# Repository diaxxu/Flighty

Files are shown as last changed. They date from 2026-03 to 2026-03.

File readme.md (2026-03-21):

flighty_wordmark<svg width="100%" viewBox="0 0 680 160" xmlns="http://www.w3.org/2000/svg"><defs><mask id="imagine-text-gaps-1nc41s" maskUnits="userSpaceOnUse"><rect x="0" y="0" width="680" height="160" fill="white"/><rect x="60.694801330566406" y="23.187637329101562" width="558.6104125976562" height="111.06857299804688" fill="black" rx="2"/></mask></defs>

  <!-- Speed lines behind text — thin diagonal strokes, left to right, rising -->
  <g stroke="#5DCAA5" stroke-linecap="round" fill="none" style="fill:none;stroke:rgb(93, 202, 165);color:rgb(255, 255, 255);stroke-width:1px;stroke-linecap:round;stroke-linejoin:miter;opacity:1;font-family:&quot;Anthropic Sans&quot;, -apple-system, BlinkMacSystemFont, &quot;Segoe UI&quot;, sans-serif;font-size:16px;font-weight:400;text-anchor:start;dominant-baseline:auto">
    <line x1="60" y1="125" x2="190" y2="55" stroke-width="0.8" opacity="0.18" mask="url(#imagine-text-gaps-1nc41s)" style="fill:none;stroke:rgb(93, 202, 165);color:rgb(255, 255, 255);stroke-width:0.8px;stroke-linecap:round;stroke-linejoin:miter;opacity:0.18;font-family:&quot;Anthropic Sans&quot;, -apple-system, BlinkMacSystemFont, &quot;Segoe UI&quot;, sans-serif;font-size:16px;font-weight:400;text-anchor:start;dominant-baseline:auto"/>
    <line x1="70" y1="132" x2="220" y2="58" stroke-width="0.5" opacity="0.12" mask="url(#imagine-text-gaps-1nc41s)" style="fill:none;stroke:rgb(93, 202, 165);color:rgb(255, 255, 255);stroke-width:0.5px;stroke-linecap:round;stroke-linejoin:miter;opacity:0.12;font-family:&quot;Anthropic Sans&quot;, -apple-system, BlinkMacSystemFont, &quot;Segoe UI&quot;, sans-serif;font-size:16px;font-weight:400;text-anchor:start;dominant-baseline:auto"/>
    <line x1="50" y1="118" x2="170" y2="52" stroke-width="0.4" opacity="0.10" mask="url(#imagine-text-gaps-1nc41s)" style="fill:none;stroke:rgb(93, 202, 165);color:rgb(255, 255, 255);stroke-width:0.4px;stroke-linecap:round;stroke-linejoin:miter;opacity:0.1;font-family:&quot;Anthropic Sans&quot;, -apple-system, BlinkMacSystemFont, &quot;Segoe UI&quot;, sans-serif;font-size:16px;font-weight:400;text-anchor:start;dominant-baseline:auto"/>
    <line x1="460" y1="108" x2="640" y2="40" stroke-width="0.8" opacity="0.18" mask="url(#imagine-text-gaps-1nc41s)" style="fill:none;stroke:rgb(93, 202, 165);color:rgb(255, 255, 255);stroke-width:0.8px;stroke-linecap:round;stroke-linejoin:miter;opacity:0.18;font-family:&quot;Anthropic Sans&quot;, -apple-system, BlinkMacSystemFont, &quot;Segoe UI&quot;, sans-serif;font-size:16px;font-weight:400;text-anchor:start;dominant-baseline:auto"/>
    <line x1="470" y1="118" x2="648" y2="48" stroke-width="0.5" opacity="0.12" mask="url(#imagine-text-gaps-1nc41s)" style="fill:none;stroke:rgb(93, 202, 165);color:rgb(255, 255, 255);stroke-width:0.5px;stroke-linecap:round;stroke-linejoin:miter;opacity:0.12;font-family:&quot;Anthropic Sans&quot;, -apple-system, BlinkMacSystemFont, &quot;Segoe UI&quot;, sans-serif;font-size:16px;font-weight:400;text-anchor:start;dominant-baseline:auto"/>
    <line x1="455" y1="100" x2="630" y2="35" stroke-width="0.4" opacity="0.10" mask="url(#imagine-text-gaps-1nc41s)" style="fill:none;stroke:rgb(93, 202, 165);color:rgb(255, 255, 255);stroke-width:0.4px;stroke-linecap:round;stroke-linejoin:miter;opacity:0.1;font-family:&quot;Anthropic Sans&quot;, -apple-system, BlinkMacSystemFont, &quot;Segoe UI&quot;, sans-serif;font-size:16px;font-weight:400;text-anchor:start;dominant-baseline:auto"/>
  </g>

  <!-- Main wordmark -->
  <text x="340" y="112" text-anchor="middle" font-family="'Rajdhani', 'Arial Narrow', sans-serif" font-size="96" font-weight="700" letter-spacing="20" fill="#5DCAA5" style="fill:rgb(93, 202, 165);stroke:none;color:rgb(255, 255, 255);stroke-width:1px;stroke-linecap:butt;stroke-linejoin:miter;opacity:1;font-family:Rajdhani, &quot;Arial Narrow&quot;, sans-serif;font-size:96px;font-weight:700;text-anchor:middle;dominant-baseline:auto"></text>

  <!-- The "I" dot replaced by a small compass rose / crosshair -->
  <!-- crosshair sits over the letter I — centered around x≈340, but "I" is the 5th letter -->
  <!-- We use a tiny crosshair as a decorative accent above the wordmark -->
  <g transform="translate(340, 28)" style="fill:rgb(0, 0, 0);stroke:none;color:rgb(255, 255, 255);stroke-width:1px;stroke-linecap:butt;stroke-linejoin:miter;opacity:1;font-family:&quot;Anthropic Sans&quot;, -apple-system, BlinkMacSystemFont, &quot;Segoe UI&quot;, sans-serif;font-size:16px;font-weight:400;text-anchor:start;dominant-baseline:auto">
    <circle cx="0" cy="0" r="7" fill="none" stroke="#9FE1CB" stroke-width="1" style="fill:none;stroke:rgb(159, 225, 203);color:rgb(255, 255, 255);stroke-width:1px;stroke-linecap:butt;stroke-linejoin:miter;opacity:1;font-family:&quot;Anthropic Sans&quot;, -apple-system, BlinkMacSystemFont, &quot;Segoe UI&quot;, sans-serif;font-size:16px;font-weight:400;text-anchor:start;dominant-baseline:auto"/>
    <line x1="-12" y1="0" x2="12" y2="0" stroke="#9FE1CB" stroke-width="1" stroke-linecap="round" style="fill:rgb(0, 0, 0);stroke:rgb(159, 225, 203);color:rgb(255, 255, 255);stroke-width:1px;stroke-linecap:round;stroke-linejoin:miter;opacity:1;font-family:&quot;Anthropic Sans&quot;, -apple-system, BlinkMacSystemFont, &quot;Segoe UI&quot;, sans-serif;font-size:16px;font-weight:400;text-anchor:start;dominant-baseline:auto"/>
    <line x1="0" y1="-12" x2="0" y2="12" stroke="#9FE1CB" stroke-width="1" stroke-linecap="round" style="fill:rgb(0, 0, 0);stroke:rgb(159, 225, 203);color:rgb(255, 255, 255);stroke-width:1px;stroke-linecap:round;stroke-linejoin:miter;opacity:1;font-family:&quot;Anthropic Sans&quot;, -apple-system, BlinkMacSystemFont, &quot;Segoe UI&quot;, sans-serif;font-size:16px;font-weight:400;text-anchor:start;dominant-baseline:auto"/>
    <circle cx="0" cy="0" r="2" fill="#5DCAA5" style="fill:rgb(93, 202, 165);stroke:none;color:rgb(255, 255, 255);stroke-width:1px;stroke-linecap:butt;stroke-linejoin:miter;opacity:1;font-family:&quot;Anthropic Sans&quot;, -apple-system, BlinkMacSystemFont, &quot;Segoe UI&quot;, sans-serif;font-size:16px;font-weight:400;text-anchor:start;dominant-baseline:auto"/>
  </g>

  <!-- Thin underline with notch — like a runway -->
  <line x1="80" y1="128" x2="600" y2="128" stroke="#1D9E75" stroke-width="1" opacity="0.5" mask="url(#imagine-text-gaps-1nc41s)" style="fill:rgb(0, 0, 0);stroke:rgb(29, 158, 117);color:rgb(255, 255, 255);stroke-width:1px;stroke-linecap:butt;stroke-linejoin:miter;opacity:0.5;font-family:&quot;Anthropic Sans&quot;, -apple-system, BlinkMacSystemFont, &quot;Segoe UI&quot;, sans-serif;font-size:16px;font-weight:400;text-anchor:start;dominant-baseline:auto"/>
  <line x1="316" y1="128" x2="364" y2="128" stroke="#9FE1CB" stroke-width="2.5" stroke-linecap="round" opacity="0.9" mask="url(#imagine-text-gaps-1nc41s)" style="fill:rgb(0, 0, 0);stroke:rgb(159, 225, 203);color:rgb(255, 255, 255);stroke-width:2.5px;stroke-linecap:round;stroke-linejoin:miter;opacity:0.9;font-family:&quot;Anthropic Sans&quot;, -apple-system, BlinkMacSystemFont, &quot;Segoe UI&quot;, sans-serif;font-size:16px;font-weight:400;text-anchor:start;dominant-baseline:auto"/>

  <!-- Tiny dots at ends of underline -->
  <circle cx="80" cy="128" r="2" fill="#1D9E75" opacity="0.5" style="fill:rgb(29, 158, 117);stroke:none;color:rgb(255, 255, 255);stroke-width:1px;stroke-linecap:butt;stroke-linejoin:miter;opacity:0.5;font-family:&quot;Anthropic Sans&quot;, -apple-system, BlinkMacSystemFont, &quot;Segoe UI&quot;, sans-serif;font-size:16px;font-weight:400;text-anchor:start;dominant-baseline:auto"/>
  <circle cx="600" cy="128" r="2" fill="#1D9E75" opacity="0.5" style="fill:rgb(29, 158, 117);stroke:none;color:rgb(255, 255, 255);stroke-width:1px;stroke-linecap:butt;stroke-linejoin:miter;opacity:0.5;font-family:&quot;Anthropic Sans&quot;, -apple-system, BlinkMacSystemFont, &quot;Segoe UI&quot;, sans-serif;font-size:16px;font-weight:400;text-anchor:start;dominant-baseline:auto"/>
</svg>

**Flighty** is my very first custom-designed flight controller! I built this to be a versatile "brain" for just about anything that flies, from standard quadcopters and fixed-wing UAVs to high-power model rockets.

I am currently using this board to power my personal RC VTOL project. It’s designed to be easy to solder (THT components), easy to repair, and a great hands-on project for anyone interested in PCB assembly.

##  Key Features

* **7x Servo/PWM Channels:** Plenty of outputs for complex RC planes, hexacopters, or VTOL transitions.
* **Rocketry Ready:** Two dedicated channels can be configured as electronic igniters (pyro-channels) for rocket motor ignition or parachute deployment.
* **Blackbox Data Logging:** Integrated **MicroSD slot** to record high-speed flight data, allowing you to re-analyze crashes or tune PID loops with precision.
* **Reliable Power Management:** Designed for **2S LiPo/Li-ion** setups with an integrated charging and protection circuit.
* **Repair-Friendly Design:** Focused on Through-Hole Technology (THT) for connectors and key components, making it durable and easy to fix in the field.

##  Hardware

* **Brain (MCU): STM32F405RGT6** – This is the heart of the board. It’s a powerful chip that handles high-frequency flight loops and complex navigation without breaking a sweat.
* **Gyro/Accel: MPU6500** – To keep things stable, I'm using the MPU6500 over I2C. It supports fast refresh rates (up to 500Hz on the bus) to keep the flight feeling smooth and responsive.
* **Altitude (Baro): BMP580** – This sensor is a beast. It’s incredibly precise, detecting altitude changes down to a few centimeters. It's perfect for a rock-steady hover or timing a rocket's parachute deployment at exactly the right moment.
* **Power: TPS63070 (Buck-Boost)** – I wanted to avoid brownouts. This regulator keeps a rock-solid 5V supplied to the sensors and MCU, even if the battery voltage drops during a hard maneuver.
* **Charging: BQ25883** – I added a built-in 2S balancer/charger. This is super convenient because you can top up your batteries directly through the board using the USB port.
* **Plug: USB Type-C** – Because nobody wants to carry around old Micro-USB cables anymore. One cable for your phone, your laptop, and your flight controller.

##  Software & Firmware

Flighty is compatible with **Ardupilot**, **INAV**, and **Betaflight**. 

> **Note:** Because this is a custom hardware layout, you will need to define a custom target (mapping the SPI/UART/PWM pins) in your chosen firmware.

---

##  Gallery

### Schematics
Flighty Schematic

### PCB Design
PCB Layout

### 3D Visuals
3D PCB View
Board Render

---

##  Bill of Materials (BOM)

| Item | Description | Quantity | Unit Price |
| :--- | :--- | :--- | :--- |
| **Flight Controller PCB** | Bare PCB from JLCPCB | 5 | $2.00 |
| **Flight Controller PCBA** | Fully Assembled Board | 2 | $130.71 |

**Project Total: $159.21**

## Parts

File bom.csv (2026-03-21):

Comment | Designator | Footprint | JLCPCB Part #
383 | RR1 | 0603 | C177271
TYPE-C16PIN2MD(073) | USB1 | USB-C-SMD_TYPE-C-6PIN-2MD-073 | C2765186
TF-01A | CARD1 | TF-SMD_TF-01A | C91145
1uF | C1,C26,C27,C28 | 0805 | C28323
LMR51430YFDDCR | U6 | SOT-23-6_L2.9-W1.6-P0.95-LS2.9-BL | C5219261
1uH | L1 | 0805 | C1042
Q13FC1350000400 | X2 | FC-135R_L3.2-W1.5 | C32346
100nF | C21,C22,C20,C31,C32,C33,C34,C35,C21,C22,C20,C31,C32,C33,C34,C35 | 0603 | C14663
MPU6500 | U1 | QFN-24_L3.0-W3.0-P0.40-BL-EP | C50278
2.2uF | C24,C25 | CP_Radial_D4.0mm_P1.50mm | C970595
30.1k | R6 | 0603 | C137745
TPS63070RNMR | U3 | VQFN-15_L3.0-W2.5-P0.50-BL | C109322
5.23k | R7 | 0603 | C2930111
SW_Push | SW1,SW2 | SW_PUSH_6mm | C83205
LED | D1 | 0603 | C2290
X322512MSB4SI | X1 | CRYSTAL-SMD_4P-L3.2-W2.5-BL | C9002
1.5uh | L2 | 0805 | C139220
47uF | C6,C4,C6,C4 | CP_Radial_D8.0mm_P5.00mm | C46895
BMP580 | U4 | LGA-10_L2.0-W2.0-P0.50-TL_BMP580 | C22391138
5.1k | R2,R3 | 0603 | C23186
0.1uF | C15,C19,C30,C7,C23,C15,C19,C30,C7,C23 | 0805 | C49678
22uF | C10,C11,C16,C17,C9 | CP_Radial_D5.0mm_P2.00mm | C43346
FCM1608KF-601T03 | L4 | L0603 | C141723
22.1k | R15 | 0603 | C100870
5.6uH | L3 | 0805 | C307698
STM32F405RGTx | U7 | LQFP-64_10x10mm_P0.5mm | C15742
6.8pF | C36,C37 | 0805 | C1832
Conn_01x03 | J2,J3,J4,J5,J6,J7,J8 | PinHeader_1x03_P2.54mm_Vertical | C49257
4.7k | R16,R17 | 0603 | C23162
10k | R10,R11,R12,R13,R18,R19,R20,R21,R22,R23,R24,R4,R5,R8,R9 | 0603 | C25804
BQ25883RGER | U5 | VFQFPN-24_L4.0-W4.0-P0.50-BL-EP2.8 | C544362
Screw_Terminal_01x02 | J1 | TerminalBlock_Xinya_XY308-2.54-2P_1x02_P2.54mm_Horizontal | C557685
100k | R14 | 0603 | C25803
10uF | C12,C13,C14,C18,C2,C29,C3,C5,C8 | CP_Radial_D5.0mm_P2.00mm | C19576

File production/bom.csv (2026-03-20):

Designator | Footprint | Quantity | Value | LCSC Part #
C1, C26, C27, C28 | 0805 | 4 | 1uF
C10, C11, C16, C17, C9 | CP_Radial_D5.0mm_P2.00mm | 5 | 22uF
C12, C13, C14, C18, C2, C29, C3, C5, C8 | CP_Radial_D5.0mm_P2.00mm | 9 | 10uF
C15, C19, C30, C7 | 0805 | 4 | 100nF
C20, C31, C32, C33, C34, C35 | 0603 | 6 | 100nF
C21, C22 | 0603 | 2 | 0.1uF
C23 | 0805 | 1 | 0.1uF
C24, C25 | CP_Radial_D4.0mm_P1.50mm | 2 | 2.2uF
C36, C37 | 0805 | 2 | 6.8pF
C4 | CP_Radial_D8.0mm_P5.00mm | 1 | 47uF
C6 | CP_Radial_D8.0mm_P5.00mm | 1 | 44uF
CARD1 | TF-SMD_TF-01A | 1 | TF-01A | C91145
D1 | 0603 | 1 | LED
J1 | TerminalBlock_Xinya_XY308-2.54-2P_1x02_P2.54mm_Horizontal | 1 | Screw_Terminal_01x02
J2, J3, J4, J5, J6, J7, J8 | PinHeader_1x03_P2.54mm_Vertical | 7 | Conn_01x03
L1 | 0805 | 1 | 1uH
L2 | 0805 | 1 | 1.5uh
L3 | 0805 | 1 | 5.6uH
L4 | L0603 | 1 | FCM1608KF-601T03 | C141723
R10, R11, R12, R13, R18, R19, R20, R21, R22, R23, R24, R4, R5, R8, R9 | 0603 | 15 | 10k
R14 | 0603 | 1 | 100k
R15 | 0603 | 1 | 22.1k
R16, R17 | 0603 | 2 | 4.7 k
R2, R3 | 0603 | 2 | 5.1k
R6 | 0603 | 1 | 30.1k
R7 | 0603 | 1 | 5.23k
RR1 | 0603 | 1 | 383
SW1, SW2 | SW_PUSH_6mm | 2 | SW_Push
U1 | QFN-24_L3.0-W3.0-P0.40-BL-EP | 1 | MPU6500 | C50278
U3 | VQFN-15_L3.0-W2.5-P0.50-BL | 1 | TPS63070RNMR | C109322
U4 | LGA-10_L2.0-W2.0-P0.50-TL_BMP580 | 1 | BMP580 | C22391138
U5 | VFQFPN-24_L4.0-W4.0-P0.50-BL-EP2.8 | 1 | BQ25883RGER | C544362
U6 | SOT-23-6_L2.9-W1.6-P0.95-LS2.9-BL | 1 | LMR51430YFDDCR | C5219261
U7 | LQFP-64_10x10mm_P0.5mm | 1 | STM32F405RGTx
USB1 | USB-C-SMD_TYPE-C-6PIN-2MD-073 | 1 | TYPE-C 16PIN 2MD(073) | C2765186
X1 | CRYSTAL-SMD_4P-L3.2-W2.5-BL | 1 | X322512MSB4SI | C9002
X2 | FC-135R_L3.2-W1.5 | 1 | Q13FC1350000400 | C32346

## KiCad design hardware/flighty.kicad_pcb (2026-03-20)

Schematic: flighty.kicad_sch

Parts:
C1: 1uF; C_0805_2012Metric
C2, C3, C5, C8, C12, C13, C14, C18: 10uF; CP_Radial_D5.0mm_P2.00mm
C4: 47uF; CP_Radial_D8.0mm_P5.00mm
C6: 44uF; CP_Radial_D8.0mm_P5.00mm
C7, C15, C19, C30: 100nF; C_0805_2012Metric
C9, C10, C11, C16, C17: 22uF; CP_Radial_D5.0mm_P2.00mm
C20, C31, C32, C33, C34, C35: 100nF; C_0603_1608Metric
C21, C22: 0.1uF; C_0603_1608Metric
C23: 0.1uF; C_0805_2012Metric
C24, C25: 2.2uF; CP_Radial_D4.0mm_P1.50mm
C26, C27, C28: 1uf; C_0805_2012Metric
C29: 10uf; CP_Radial_D5.0mm_P2.00mm
C36, C37: 6.8pF; C_0805_2012Metric
Card1: TF-01A; TF-SMD_TF-01A; LCSC Part C91145
D1: LED; LED_0603_1608Metric
J1: Screw_Terminal_01x02; TerminalBlock_Xinya_XY308-2.54-2P_1x02_P2.54mm_Horizontal
J2, J3, J4, J5, J6, J7, J8: Conn_01x03; PinHeader_1x03_P2.54mm_Vertical
L1: 1uH; L_0805_2012Metric
L2: 1.5uh; L_0805_2012Metric
L3: 5.6uH; L_0805_2012Metric
L4: FCM1608KF-601T03; L0603; LCSC Part C141723
R2, R3: 5.1k; R_0603_1608Metric
R4, R8, R9, R10, R11, R12, R24: 10k; R_0603_1608Metric
R5, R13, R18, R19, R20, R21, R22, R23: 10K; R_0603_1608Metric
R6: 30.1k; R_0603_1608Metric
R7: 5.23k; R_0603_1608Metric
R14: 100k; R_0603_1608Metric
R15: 22.1k; R_0603_1608Metric
R16, R17: 4.7 k; R_0603_1608Metric
RR1: 383; R_0603_1608Metric
SW1, SW2: SW_Push; SW_PUSH_6mm
U1: MPU6500; QFN-24_L3.0-W3.0-P0.40-BL-EP; LCSC Part C50278
U3: TPS63070RNMR; VQFN-15_L3.0-W2.5-P0.50-BL; LCSC Part C109322
U4: BMP580; LGA-10_L2.0-W2.0-P0.50-TL_BMP580; LCSC Part C22391138
U5: BQ25883RGER; VFQFPN-24_L4.0-W4.0-P0.50-BL-EP2.8; LCSC Part C544362
U6: LMR51430YFDDCR; SOT-23-6_L2.9-W1.6-P0.95-LS2.9-BL; LCSC Part C5219261
U7: STM32F405RGTx; LQFP-64_10x10mm_P0.5mm
USB1: TYPE-C 16PIN 2MD(073); USB-C-SMD_TYPE-C-6PIN-2MD-073; LCSC Part C2765186
X1: X322512MSB4SI; CRYSTAL-SMD_4P-L3.2-W2.5-BL; LCSC Part C9002
X2: Q13FC1350000400; FC-135R_L3.2-W1.5; LCSC Part C32346

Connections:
+3.3V: C16.1, C17.1, C19.1, C20.1, C21.2, C22.2, C26.1, C27.1, C28.1, C29.1, C30.1, C31.1, C32.1, C33.1, C34.1, Card1.4 (VDD), L3.2, L4.2, R16.1, R17.1, R18.1, R19.1, R20.1, R21.1, R22.1, R23.1, SW2.2, U1.8 (VDDIO), U1.9 (SDO/AD0), U1.13 (VDD), U1.22 (nCS), U4.1 (VDDIO), U4.10 (VDD), U7.1 (VBAT), U7.19 (VDD), U7.32 (VDD), U7.48 (VDD), U7.64 (VDD)
+5V: C8.2, C9.2, C10.2, C11.2, J2.2, J3.2, J4.2, J5.2, J6.2, J7.2, J8.2, R5.2, R8.1, U3.5 (FB), U3.7 (Vout), U3.8 (Vout)
+BATT: C5.1, J1.1, U5.13 (BAT), U5.14 (BAT)
/BMP_INT: U4.7 (INT), U7.36 (PB15)
/BMP_SCL: U4.2 (SCK), U7.58 (PB6)
/BMP_SDA: U4.4 (SDI), U7.59 (PB7)
/BQ_CE: U5.3 (~CE), U7.37 (PC6)
/BQ_INT: R10.2, U5.6 (~INT), U7.38 (PC7)
/BQ_PG: R8.2, U5.9 (~PG)
/BQ_SCL: R11.2, U5.5 (SCL)
/BQ_SDA: R12.2, U5.4 (SDA)
/BTST: C4.1, L1.2, U5.17 (SW), U5.18 (SW)
/MPU_INT: U1.12 (INT), U7.35 (PB14)
/MPU_SCL: R17.2, U1.23 (SCL/SCLK), U7.29 (PB10)
/MPU_SDA: R16.2, U1.24 (SDA/SDI), U7.30 (PB11)
/SD_CD: Card1.9 (CD)
/SD_CLK: Card1.5 (CLK(SCLK)), R23.2, U7.53 (PC12)
/SD_CMD: Card1.3 (CMD(DI)), R22.2, U7.54 (PD2)
/SD_DAT0: Card1.7 (DAT0(D0)), R21.2, U7.39 (PC8)
/SD_DAT1: Card1.8 (DAT1(RSV)), R20.2, U7.40 (PC9)
/SD_DAT2: Card1.1 (DAT2(RSV)), R19.2, U7.51 (PC10)
/SD_DAT3: Card1.2 (CDDAT3(CS)), R18.2, U7.52 (PC11)
/SERVO_1: J3.1, U7.61 (PB8)
/SERVO_2: J2.1, U7.62 (PB9)
/SERVO_3: J4.1, U7.55 (PB3)
/SERVO_4: J5.1, U7.16 (PA2)
/SERVO_5: J6.1, U7.17 (PA3)
/SERVO_6: J7.1, U7.21 (PA5)
/SERVO_7: J8.1, U7.22 (PA6)
/USB_DN: U7.44 (PA11), USB1.5 (DN2), USB1.7 (DN1)
/USB_DP: U7.45 (PA12), USB1.6 (DP1), USB1.8 (DP2)
/USB_vbus: USB1.2 (VBUS), USB1.11 (VBUS)
GND: C2.2, C3.2, C5.2, C6.2, C7.1, C8.1, C9.1, C10.1, C11.1, C12.1, C13.1, C14.1, C16.2, C17.2, C18.2, C19.2, C20.2, C21.1, C22.1, C23.1, C24.1, C25.1, C26.2, C27.2, C28.2, C29.2, C30.2, C31.2, C32.2, C33.2, C34.2, C36.1, C37.2, Card1.6 (VSS), Card1.10 (GND), Card1.11 (GND), J2.3, J3.3, J4.3, J5.3, J6.3, J7.3, J8.3, R2.1, R3.1, R4.2, R6.2, R15.2, R24.1, RR1.2, SW1.1, U1.11 (FSYNC), U1.18 (GND), U3.4 (GND), U3.6 (FB2), U3.10 (PGND), U3.15 (Vsel), U4.3 (VSS), U4.5 (SDO), U4.6 (CSB), U4.8 (VSS), U4.9 (VSS), U5.19 (GND), U5.20 (GND), U6.1 (GND), U7.12 (VSSA), U7.18 (VSS), U7.63 (VSS), USB1.1 (GND), USB1.12 (GND), USB1.13 (SHELL), USB1.14 (SHELL), X1.2 (GND), X1.4 (GND)
unnamed: C2.1, L1.1, U5.21 (PMID), U5.22 (PMID)
unnamed: C35.1, SW1.2
unnamed: D1.2 (A), R9.1
unnamed: D1.1 (K), U5.2 (STAT)
unnamed: R9.2, R10.1, R11.1, R12.1
unnamed: C23.2, U1.10 (REGOUT)
unnamed: R13.1, U3.1 (PS/SYNC), U3.14 (EN)
unnamed: L2.1, U3.11 (L1)
unnamed: L2.2, U3.9 (L2)
unnamed: R5.1, U3.2 (PG)
unnamed: C7.2, U3.3 (Vaux)
unnamed: C4.2, U5.12 (BTST)
unnamed: RR1.1, U5.8 (ILIM)
unnamed: R4.1, R6.1, R7.2, U5.7 (TS)
unnamed: C15.2, U6.6 (CB)
unnamed: R14.2, R15.1, U6.4 (FB)
unnamed: C15.1, L3.1, R14.1, U6.2 (SW)
unnamed: R24.2, SW2.1, U7.60 (BOOT0)
unnamed: C35.2, U7.7 (NRST)
unnamed: C37.1, U7.3 (PC14), X2.1
unnamed: C36.2, U7.4 (PC15), X2.2
unnamed: U7.5 (PH0), X1.1 (OSC1)
unnamed: U7.6 (PH1), X1.3 (OSC2)
unnamed: C24.2, U7.31 (VCAP_1)
unnamed: C25.2, U7.47 (VCAP_2)
unnamed: L4.1, U7.13 (VDDA)
unnamed: R3.2, USB1.4 (CC1)
unnamed: R2.2, USB1.10 (CC2)
PGND: C1.1, J1.2, U5.25 (EP)
VREGN: C3.1, R7.1, U5.11 (REGN)
VSYS: C6.1, C12.2, C13.2, C14.2, C18.1, R13.2, U3.12 (Vin), U3.13 (Vin), U5.16 (SYS), U6.3 (VIN), U6.5 (EN)
vbus: C1.2, U5.23 (VBUS)

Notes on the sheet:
flight controller

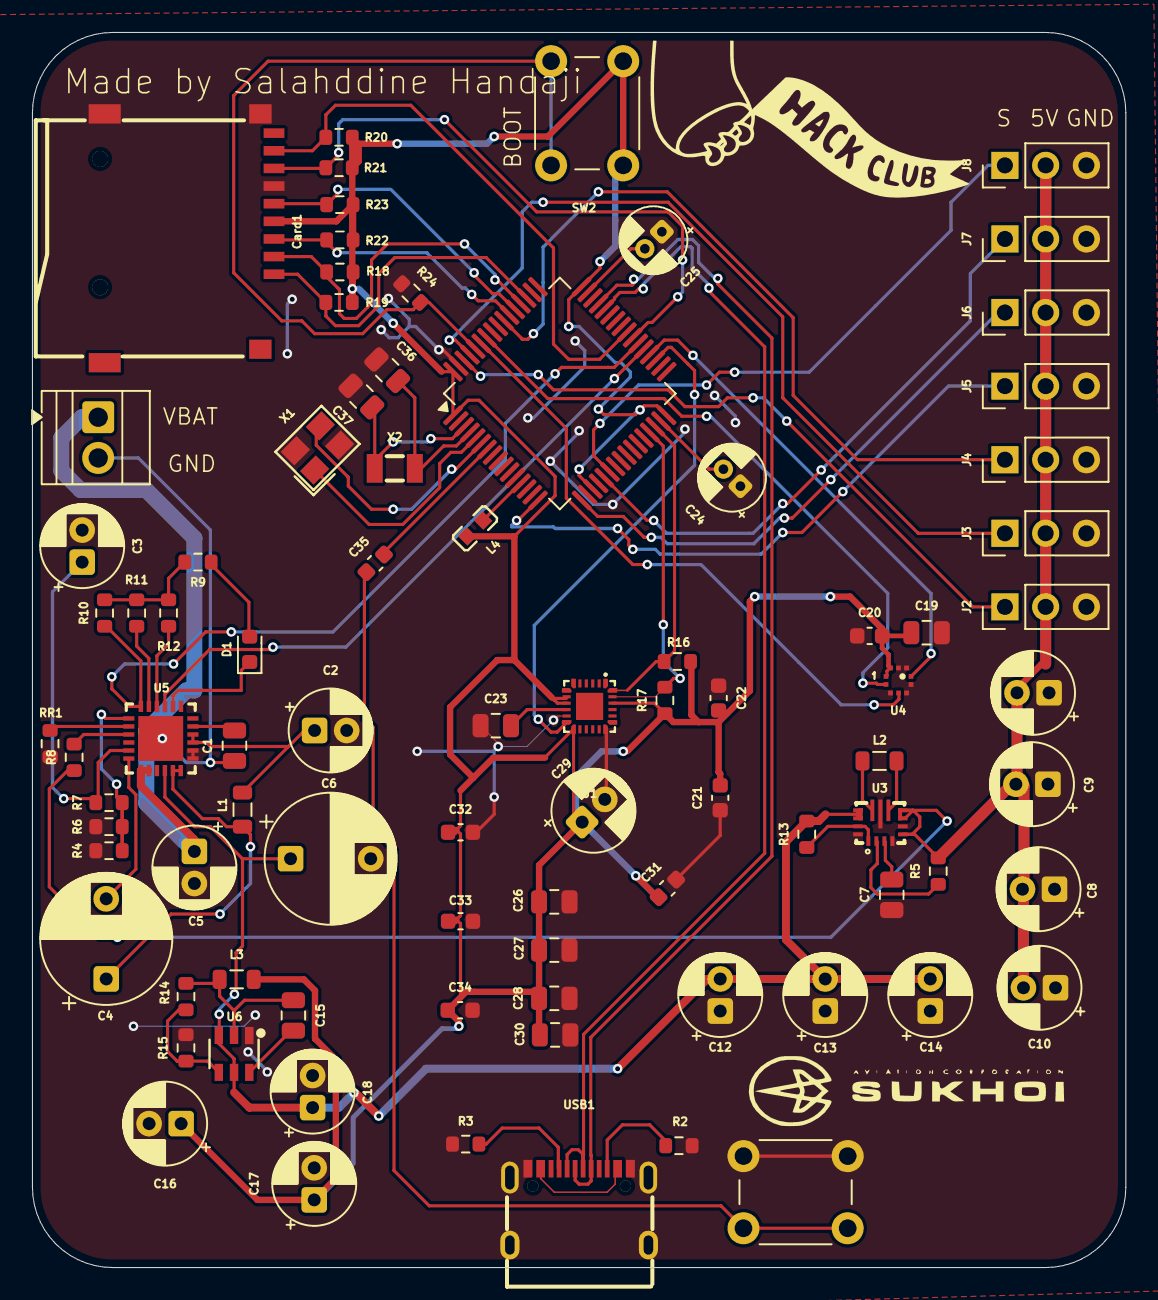
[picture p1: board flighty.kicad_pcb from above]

Board: 2 copper layers, 68.2 x 77.0 mm, 86 parts (0 on the bottom side), 64 nets.

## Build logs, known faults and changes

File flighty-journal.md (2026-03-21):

<!--
  This journal is auto generated by Hack Club Blueprint.
-->

# 3/15/2026 - Researching and watching explanatory videos  

_Time spent: 1.0h_  

i am currently watching and reading on how to design flight controller i hope to be able to finish this project before the end of blueprint im following notaroomba guide 

# 3/16/2026 - advancements  

_Time spent: 8.3h_  

well i started designing the flight controller i named it Flighty 
I started by selection of the component the goals and its needs the schematics i made it to be easily solderable and cheap to repair i will be using THT components  Capture d'écran 2026-03-16 034847
 Capture d'écran 2026-03-15 235632
Capture d'écran 2026-03-15 235618
Capture d'écran 2026-03-15 235625

Capture d'écran 2026-03-16 033853

Capture d'écran 2026-03-16 092545
- the fully finished schematics

Capture d'écran 2026-03-16 070459Capture d'écran 2026-03-16 085831Capture d'écran 2026-03-16 092552Capture d'écran 2026-03-16 085523Capture d'écran 2026-03-16 092615
Capture d'écran 2026-03-16 092608
Capture d'écran 2026-03-16 085514Capture d'écran 2026-03-16 085548
### 3d renders

# 3/18/2026 2 PM - new mission  

_Time spent: 2.0h_  

after putting my flighcontroller in jlcpcb i saw that the component i choose were very bad choice either rare and expensive or unavailable no suprise that my flightcontroller cost 194$ Capture d'écran 2026-03-18 140119
so i changed every component that was deemed to big and not exact to reduce cost  but when returning to check on the pcb ... everything was combled finally i took the decision to restart the routing this time better than last and even smaller 

# 3/18/2026 5:09 PM - Remake  

_Time spent: 2.0h_  

finished the remake it looks much better  i will try to setup the github add a readme and the correct structure to hopefully pass and get my flightcontroller between my hands


# 3/18/2026 5:54 PM - jlc phase  

_Time spent: 0.4h_  

i uploaded the zip file and the bom and cpl to jlc pcb Capture d'écran 2026-03-18 174217 after a lot of choosing component i finally got that result 
Unfortunately there is still some component non available showing as shortfall i will try to replace them without changing too much 
here is the price honestly i was happy because from the last try it was 190 dollar now its 130dollar
 Capture d'écran 2026-03-18 174911 next session i will replace the shortfall components :) and set up the readme

# 3/20/2026 - changed the shortfall component  

_Time spent: 4.0h_  

i changed the shortfallEd components so that i can manufacture them also i did some upgrade to the flight controller like i widened the 5v traces and 3.3v traces Capture d'écran 2026-03-19 112951Capture d'écran 2026-03-19 112940
in jlc pcb 



### i selected 2 pcba and 5 pcb for the cheapest outcome



 i have some coupon but i the 20dollar one will expire in 6hours i will play it safe and choose the 9 dollar coupon so even if the coupon expire i can still pay 

so here is the final price

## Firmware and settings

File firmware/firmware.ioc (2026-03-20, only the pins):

Mcu.UserName=STM32F405RGTx
PA11.Signal=USB_OTG_FS_DM
PA12.Signal=USB_OTG_FS_DP
PA13.Signal=SYS_JTMS-SWDIO
PA14.Signal=SYS_JTCK-SWCLK
PA2.Signal=S_TIM2_CH3
PA3.Signal=S_TIM2_CH4
PA5.Signal=S_TIM2_CH1_ETR
PA6.Signal=S_TIM13_CH1
PB10.Signal=I2C2_SCL
PB11.Signal=I2C2_SDA
PB13.GPIO_Label=SD_DET
PB13.Signal=GPIO_Input
PB14.GPIO_Label=MPU_INT
PB14.Signal=GPXTI14
PB15.GPIO_Label=BMP_INT
PB15.Signal=GPXTI15
PB3.Signal=S_TIM2_CH2
PB6.Signal=I2C1_SCL
PB7.Signal=I2C1_SDA
PB8.Signal=S_TIM10_CH1
PB9.Signal=S_TIM11_CH1
PC10.Signal=SDIO_D2
PC11.Signal=SDIO_D3
PC12.Signal=SDIO_CK
PC14-OSC32_IN.Signal=RCC_OSC32_IN
PC15-OSC32_OUT.Signal=RCC_OSC32_OUT
PC6.GPIO_Label=BQ_CE
PC6.Signal=GPIO_Output
PC7.GPIO_Label=BQ_INT
PC7.Signal=GPXTI7
PC8.Signal=SDIO_D0
PC9.Signal=SDIO_D1
PD2.Signal=SDIO_CMD
PH0-OSC_IN.Signal=RCC_OSC_IN
PH1-OSC_OUT.Signal=RCC_OSC_OUT

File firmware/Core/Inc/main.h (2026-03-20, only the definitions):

#define SD_DET_Pin GPIO_PIN_13
#define SD_DET_GPIO_Port GPIOB
#define MPU_INT_Pin GPIO_PIN_14
#define MPU_INT_GPIO_Port GPIOB
#define BMP_INT_Pin GPIO_PIN_15
#define BMP_INT_GPIO_Port GPIOB
#define BQ_CE_Pin GPIO_PIN_6
#define BQ_CE_GPIO_Port GPIOC
#define BQ_INT_Pin GPIO_PIN_7
#define BQ_INT_GPIO_Port GPIOC

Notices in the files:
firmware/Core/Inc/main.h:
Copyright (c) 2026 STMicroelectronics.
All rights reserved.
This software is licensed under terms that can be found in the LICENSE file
